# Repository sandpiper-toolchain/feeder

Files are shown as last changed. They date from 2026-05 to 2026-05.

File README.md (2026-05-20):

# feeder

Open-source sediment feeders for geomorphology experiments.

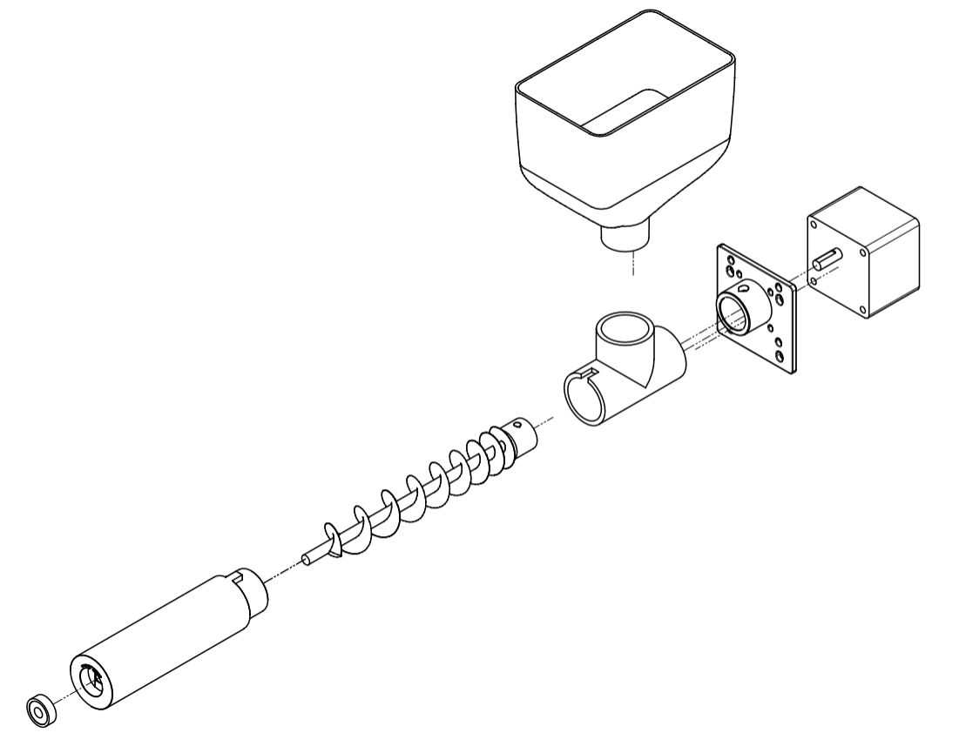
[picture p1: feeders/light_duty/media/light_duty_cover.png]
exploded light duty feeder


## Getting started

A single feeder setup consists of a "motor assembly" and a "feeder".
To the maximum extent possible any of the described motor assemblies and feeders can be mixed-and-matched to create a complete feeder setup.

Motors may be controlled manually, or with the provided microcontroller code.

This repository provides the information to build the following:

**feeders**

* [light_duty](/feeders/light_duty/)
* ~standard~ (not yet available)

**motor assemblies**

* [manual_control_ac_motor](/motor_assemblies/)
* ~multi_control_dc_motor~ (not yet available)

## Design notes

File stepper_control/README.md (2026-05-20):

# Stepper Motor Sediment Feeder

> **Note:** This README was generated with AI assistance. While it reflects the actual code and hardware used in this project, some details (library versions, port names, wiring notes) may be inaccurate or become outdated. Verify against the source files and your hardware before following any instructions.

A CircuitPython firmware package for the Raspberry Pi Pico that drives a laboratory sediment feeder. A stepper motor controls a hopper/auger mechanism to dispense sediment at a programmable, adjustable rate. Speed and direction can be set manually via a rotary encoder and hardware buttons, or remotely from a PC over USB serial.

---

## Hardware Components

| Component | Description | Notes |
|---|---|---|
| Raspberry Pi Pico | RP2040 microcontroller | Standard Pico (not Pico W) |
| Stepper motor | NEMA stepper with step/dir/enable driver | Tested at 400 steps/rev |
| Stepper motor driver | A4988, DRV8825, or similar | Must expose STEP, DIR, and ENA pins |
| [Adafruit I2C Rotary Encoder Breakout](https://www.adafruit.com/product/4991) | Seesaw-based encoder with button | Product ID 4991, I2C addr `0x36` |
| SSD1306 OLED display | 128×64 monochrome, I2C | I2C addr `0x3D` |
| 3× momentary push buttons | Through-hole or panel-mount | Pulled down internally via Pico GPIO |

---

## Pin Wiring

| Pico Pin | Function |
|---|---|
| GP4 (SDA) | I2C data — shared bus for OLED and encoder |
| GP5 (SCL) | I2C clock — shared bus for OLED and encoder |
| GP8 | Button C — stop/exit program |
| GP9 | OLED reset |
| GP10 | Button B — reverse motor direction |
| GP15 | Button A — toggle motor enable |
| GP18 | Stepper STEP (PWM output) |
| GP19 | Stepper DIR |
| GP22 | Stepper ENA |

The three GPIO buttons connect between the pin and GND; the firmware configures them with internal pull-downs, so they read HIGH when pressed.

---

## Software Requirements

### CircuitPython

Install **CircuitPython 9.2.x** on the Pico:

1. Download the UF2 from [circuitpython.org](https://circuitpython.org/board/raspberry_pi_pico/).
2. Hold BOOTSEL on the Pico and plug in USB; drag the UF2 to the `RPI-RP2` drive.

### Libraries

Copy the following from the [Adafruit CircuitPython Bundle](https://circuitpython.org/libraries) into the `lib/` folder on the Pico:

| Library | Source |
|---|---|
| `adafruit_seesaw/` | Adafruit CircuitPython Seesaw |
| `adafruit_displayio_ssd1306.py` | Adafruit CircuitPython DisplayIO SSD1306 |
| `adafruit_display_text/` | Adafruit CircuitPython Display Text |
| `adafruit_bus_device/` | Adafruit CircuitPython BusDevice |
| `adafruit_motor/` | Adafruit CircuitPython Motor |
| `adafruit_pixelbuf.mpy` | Adafruit CircuitPython Pixelbuf |
| `adafruit_ht16k33/` | Adafruit CircuitPython HT16K33 |

The following are built into CircuitPython and require no separate install: `pwmio`, `digitalio`, `displayio`, `busio`, `supervisor`, `usb_cdc`.

---

## Project Files

| File | Purpose |
|---|---|
| `boot.py` | Runs at power-on; enables dual USB CDC endpoints (console + data) |
| `stepper.py` | `Stepper` class — low-level motor control via PWM and GPIO |
| `code.py` | Main application — display, encoder, buttons, serial command loop |

---

## Getting Started

1. Wire up the hardware per the pin table above.
2. Flash CircuitPython and copy the `lib/` folder to the Pico.
3. Copy `boot.py`, `stepper.py`, and `code.py` to the root of the Pico (`CIRCUITPY` drive).
4. The Pico will reboot and start the feeder firmware automatically.

The OLED will show **"Feeder initialized."** briefly, then display live status:

```
speed: 0.080 Hz
motor is: OFF
direction is: CW
enable pin is: ON
```

---

## Manual Controls

| Control | Action |
|---|---|
| Rotate encoder knob | Increase / decrease motor speed |
| Press encoder knob | Toggle motor start / stop |
| Button A (GP15) | Toggle motor enable (releases coil torque when OFF) |
| Button B (GP10) | Reverse motor direction (CW ↔ CCW) |
| Button C (GP8) | Exit the program (stops motor cleanly) |

---

## PC-Side Python Setup

To send commands from a PC you need the `pyserial` package. Using a virtual environment keeps this isolated from your system Python.

### Create and activate a venv

**Linux / macOS:**
```bash
python3 -m venv feeder-env
source feeder-env/bin/activate
```

**Windows:**
```bat
python -m venv feeder-env
feeder-env\Scripts\activate
```

### Install dependencies

```bash
pip install pyserial
```

To save the environment for later:
```bash
pip freeze > requirements.txt
```

To restore it on another machine:
```bash
pip install -r requirements.txt
```

### Find the correct serial ports

When the Pico is plugged in, it will appear as two serial ports — one for the console and one for data. To find them:

**Linux:**
```bash
ls /dev/ttyACM*
# typically /dev/ttyACM0 (console) and /dev/ttyACM1 (data)
```

**macOS:**
```bash
ls /dev/tty.usbmodem*
```

**Windows:** Open Device Manager and look under **Ports (COM & LPT)** for two new COM ports.

---

## Remote Control via USB Serial

The Pico exposes two USB serial ports when connected to a PC:

- **Console port** — receives commands and prints debug output.
- **Data port** — returns telemetry responses to `get:` queries.

Send commands as plain text lines (terminated with `\n`) to the **console port**.

### Commands

| Command | Description |
|---|---|
| `speed=<float>` | Set motor speed in rotations per second (e.g. `speed=0.5`) |
| `toggle` | Start or stop the motor |
| `switch_direction` | Reverse motor direction |
| `enable` | Enable motor driver |
| `disable` | Disable motor driver (releases torque) |
| `get:speed` | Query current speed (RPS) — response on data port |
| `get:direction` | Query direction (`-1`=CW, `1`=CCW) — response on data port |
| `get:enabled` | Query enable state (`True`/`False`) — response on data port |
| `get:running` | Query running state (`True`/`False`) — response on data port |
| `stop` | Exit the program |

### Example (Python on PC)

```python
import serial, time

# Adjust port names for your OS (e.g. 'COM3' on Windows, '/dev/ttyACM0' on Linux)
console = serial.Serial('/dev/ttyACM0', timeout=1)
dataport = serial.Serial('/dev/ttyACM1', timeout=1)

console.write(b'speed=0.25\n')   # set 0.25 RPS
time.sleep(0.1)
console.write(b'toggle\n')       # start motor

console.write(b'get:speed\n')
print(dataport.readline())       # b'0.25\n'
```

---

## Stepper Class Reference

`stepper.py` provides the `Stepper` class used by `code.py`, but can be imported into any CircuitPython project:

```python
from stepper import Stepper
import board

s = Stepper(
    step_pin=board.GP18,
    dir_pin=board.GP19,
    ena_pin=board.GP22,
    steps_per_rev=400,   # match your motor/driver microstepping setting
    speed_sps=800        # initial speed in steps per second
)

s.start()              # begin stepping
s.speed_rps(0.5)       # change to 0.5 RPS
s.change_direction()   # reverse
s.stop()               # halt and disable
```

`steps_per_rev` should match your driver's microstepping setting (e.g. 400 for half-step, 1600 for 1/8, 3200 for 1/16).

---

## License

MIT License — Eric Barefoot, 2025. Encoder example adapted from Adafruit (John Furcean, 2021, MIT).

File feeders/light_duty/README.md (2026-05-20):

# light duty feeder

This feeder was designed to deliver rice grains for "rice pile" type experiments.

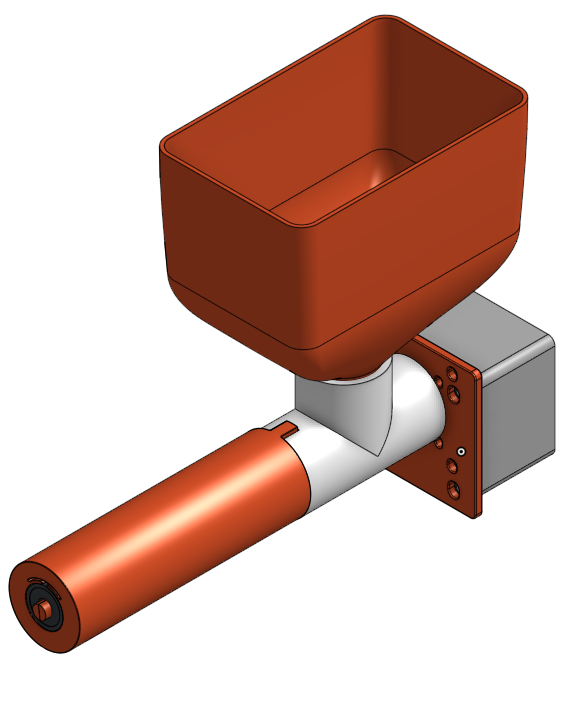
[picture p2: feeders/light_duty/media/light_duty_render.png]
light duty feeder assembly rendered


A driving design principle for the light duty feeder is extremely low cost.
This has been achieved by using an off-the-shelf plumbing part for the main feeder housing, and standard hardware and mounting configurations. 

This feeder may not be suitable for clastic sediments, due to the inherent strength of 3D-printed materials.
The design and print instructions are optimized for easy printing and maximum strength for FDM printing.  

## Bill of Materials

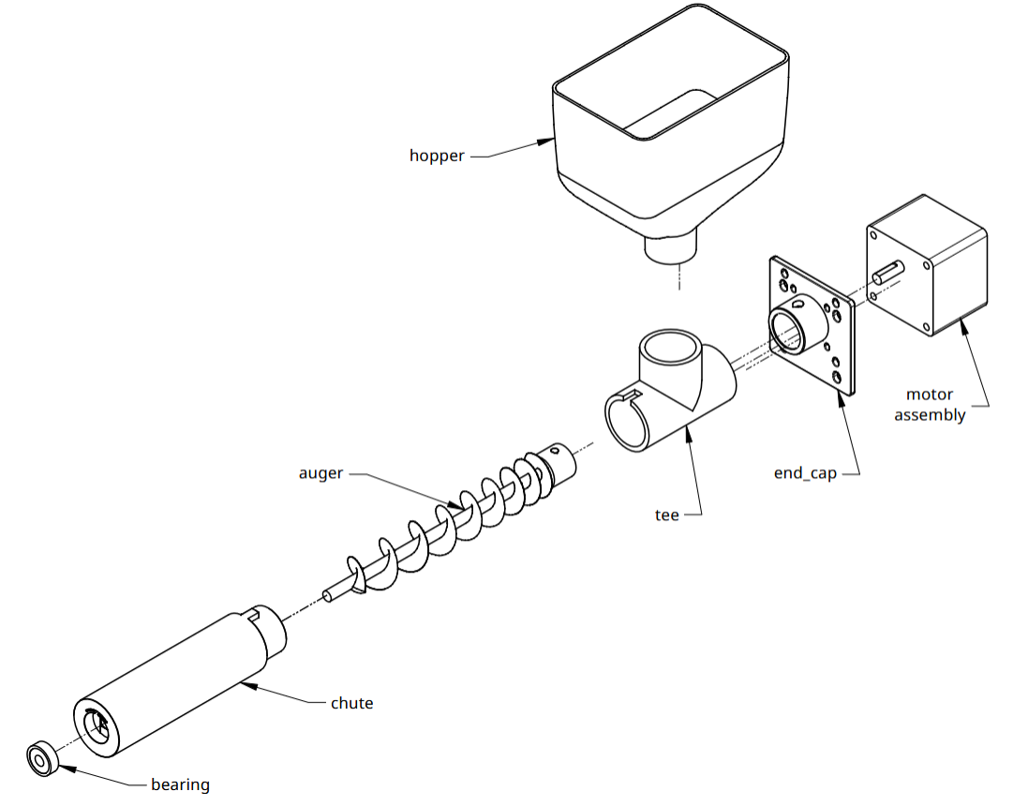
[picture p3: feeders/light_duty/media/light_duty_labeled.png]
exploded light duty feeder


* 1 x 1 inch schedule 40 PVC tee connector
* 1 x 608RS bearing
* 1 x M4 nut
* 1 x M4 by 5 mm set screw
* [a motor assembly](/motor_assemblies/) with 8 mm output shaft, and appropriate mounting screws
* 3D-printed components (see below)
* CA glue

You also will need standard tools, likely including Allen wrenches, a hacksaw, a screwdriver, etc.

## Instructions and build notes

### Build notes

* The `end_cap` has mounting holes for NEMA 17 and 23 stepper motors, as well as the AC motor listed in the motor assembly section. 
* The `chute` has a mounting point for a 608 bearing. The feeder may function fine without the bearing, but will have considerably more play in the auger shaft.
* The `auger` is designed for a motor assembly with an 8 mm D shaft.

### Printing

**.stl files are found above in the folder vX.X.**

All components can be printed in material of your choice. 
PLA works well, but PETG or ABS may provide stronger components. 
Both textured and flat build plates will be fine. 
All parts can be printed with 15% infill, except the `auger`, which should be printed at 100% infill.

* The `auger` halves should be printed with the flat side down, and then glued together with CA glue. 
  * This part should be printed at 100% infill.
  * If you would like to print the `auger` in a resin printer, an unsplit auger .stl file is also provided.
* The `chute` should be printed on the bearing side. 
* The `end_cap` should be printed on motor side.
* The `hopper` should be printed on the wide end (i.e., upside down). 

### Assembly

After printing all components:
1. Using a saw, cut a small notch in end of one side of the long edge of the PVC tee, with the notch on the same side as the short side of the tee. The notch should be larger than the corresponding block on the `chute` (cut a ~7 mm  wide by ~11 mm deep notch); it is okay if the notch is slightly larger than needed creating some play, but try to keep it at tight as possible.
1. Insert the bearing into the back of the `chute`.
1. Insert the M4 nut into the back of the `auger`. You can use some CA glue to hold the nut in place, but it is not necessary.  
1. Attach the `end_cap` to motor face using appropriate screws and mounting holes.
1. Slide the `auger` onto the motor output shaft, and tighten M4 set screw onto flat of D output shaft.
1. Slide the `chute` over the `auger`, and carefully align block with notch in PVC tee and `auger` end with inner bearing hole. Some force may be required to seat the `auger` end into the inner bearing hole.
1. Insert the `hopper` into PVC tee.
1. Fill `hopper` with granular material, provide power to motor assembly.

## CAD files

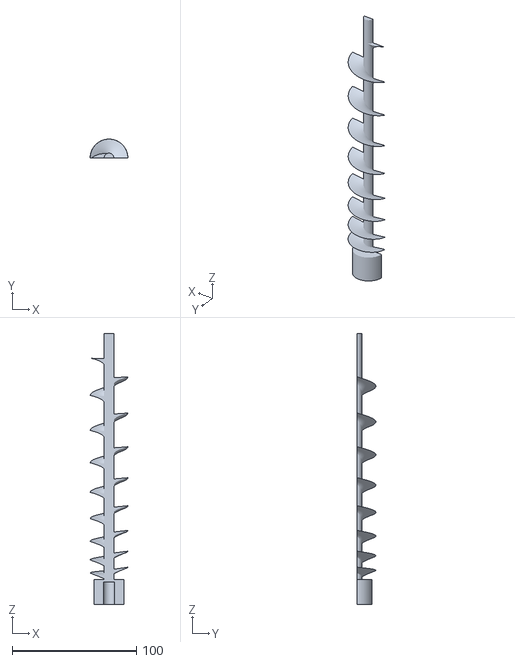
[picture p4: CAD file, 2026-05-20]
feeders/light_duty/v0.1/auger_1.stl
30.4 x 15.2 x 218.0

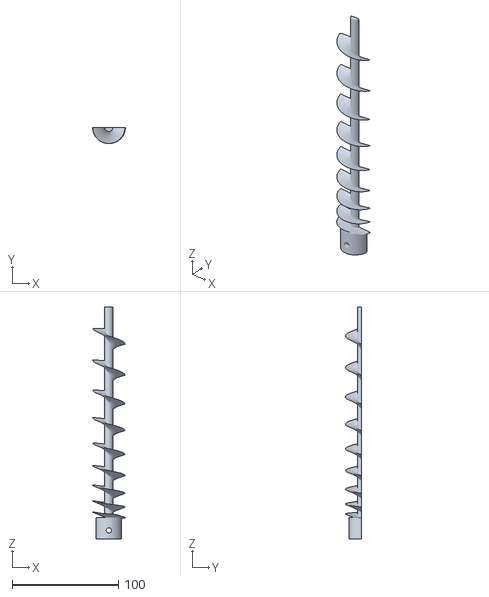
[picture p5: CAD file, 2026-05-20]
feeders/light_duty/v0.1/auger_2.stl
30.8 x 15.3 x 218.0

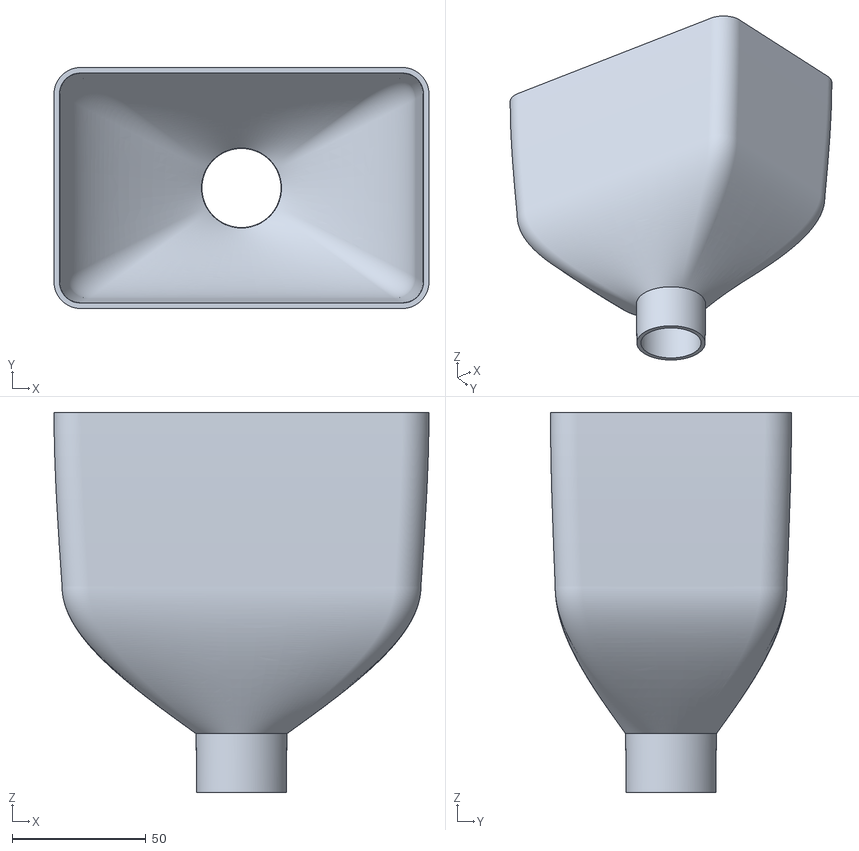
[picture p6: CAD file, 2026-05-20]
feeders/light_duty/v0.1/hopper.stl
140.0 x 90.0 x 142.0

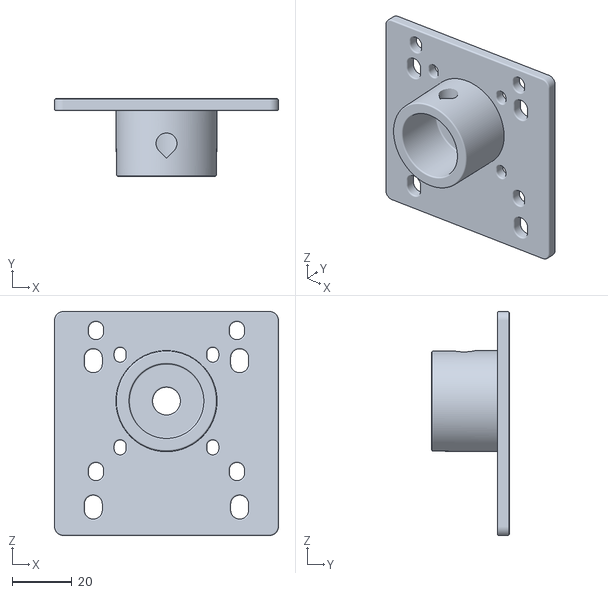
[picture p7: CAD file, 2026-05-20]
feeders/light_duty/v0.1/end_cap.stl
75.0 x 26.0 x 75.0

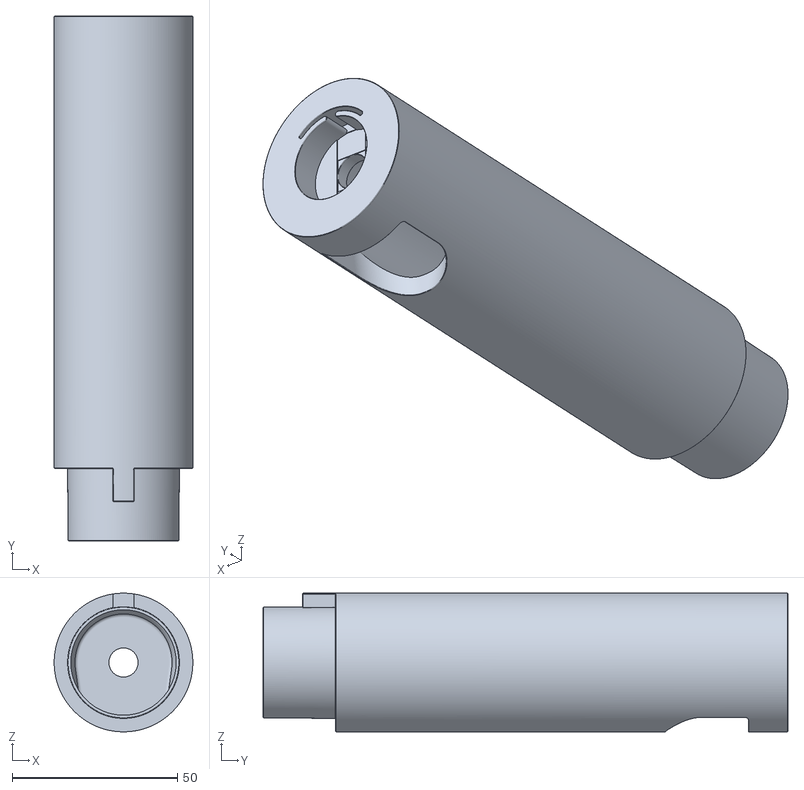
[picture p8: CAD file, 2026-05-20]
feeders/light_duty/v0.1/chute.stl
42.0 x 159.0 x 42.0

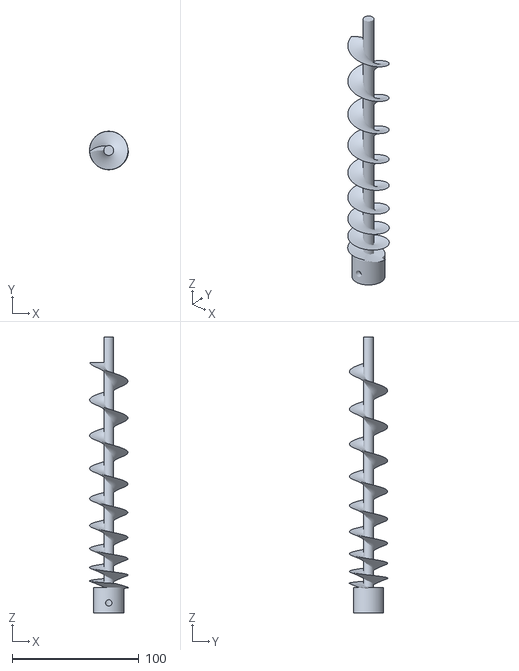
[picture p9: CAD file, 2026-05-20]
feeders/light_duty/v0.1/auger_unsplit.stl
30.8 x 30.5 x 218.0

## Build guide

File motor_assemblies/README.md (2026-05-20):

# motor assemblies

You can use any `motor_assembly` to power any `feeder`, including your own motor assembly that is not listed below.

* We have successfully used DC brushed and brushless motors, AC motors, and stepper motors.
* In general, you want something that can provide a relatively large amount of torque at low RPM.
* In general, you do not need a motor with a top end of more than 100 RPM.

There are many thousands of different motors available on the internet across sites like Amazon, Alibaba, DFRobot, Adafruit, etc. 

## Described assemblies

**manual_control_ac_motor**

You can buy a complete motor assembly that includes a power cord, control knob, and motor mount, and the motor itself. 
For example, [this AC motor from Amazon](https://www.amazon.com/dp/B07WH5V14Z). 

This is probably the easiest motor assembly to "build" to run one of the feeders, because there is essentially zero assembly required.

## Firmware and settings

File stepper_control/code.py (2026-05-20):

"""Sediment feeder controller for Raspberry Pi Pico.

Main application firmware for the laboratory sediment feeder. Manages stepper motor
control, displays real-time status on OLED, handles user input from rotary encoder
and buttons, and accepts remote commands via USB serial for PC integration.

SPDX-FileCopyrightText: 2021 John Furcean
SPDX-License-Identifier: MIT
Modified by Eric Barefoot MIT LICENSE 2025
"""

import board
from time import sleep, monotonic
import digitalio

# USB serial endpoints for remote control and telemetry
from usb_cdc import console as conser
from usb_cdc import data as dataline

from supervisor import runtime

# Disable autoreload to prevent interruption during experiments
runtime.autoreload = False
print(f"AutoReload is {runtime.autoreload=}")

# Stepper motor control (GPIO pins GP18=step, GP19=direction, GP22=enable)
from stepper import Stepper

from adafruit_seesaw import rotaryio, seesaw
from adafruit_seesaw import digitalio as ssdio

s = Stepper(step_pin=board.GP18, dir_pin=board.GP19, ena_pin=board.GP22, steps_per_rev=400)
# TODO: Make steps_per_rev configurable to support different motor types

# Display and input hardware (I2C bus on GP4=SDA, GP5=SCL)
import displayio
import i2cdisplaybus
import adafruit_displayio_ssd1306
import terminalio
from adafruit_display_text import label

displayio.release_displays()

import busio
i2c = busio.I2C(scl=board.GP5, sda=board.GP4)

# Seesaw breakout (addr 0x36) hosts rotary encoder and knob button
seesaw = seesaw.Seesaw(i2c, addr=0x36)

seesaw_product = (seesaw.get_version() >> 16) & 0xFFFF
if seesaw_product != 4991:
    print("Wrong firmware loaded?  Expected 4991")

# Rotary encoder knob button (on seesaw pin 24)
seesaw.pin_mode(24, seesaw.INPUT_PULLUP)
button = ssdio.DigitalIO(seesaw, 24)
button_held = False

# Rotary encoder for speed control
encoder = rotaryio.IncrementalEncoder(seesaw)

# Control buttons on Pico GPIO
# Button A (GP15): Toggle motor enable
# Button B (GP10): Change direction
# Button C (GP8): Stop/exit program
button_a = digitalio.DigitalInOut(board.GP15)
button_a.direction = digitalio.Direction.INPUT
button_a.pull = digitalio.Pull.DOWN

button_b = digitalio.DigitalInOut(board.GP10)
button_b.direction = digitalio.Direction.INPUT
button_b.pull = digitalio.Pull.DOWN

button_c = digitalio.DigitalInOut(board.GP8)
button_c.direction = digitalio.Direction.INPUT
button_c.pull = digitalio.Pull.DOWN

# led = digitalio.DigitalInOut(board.GP25)
# led.direction = digitalio.Direction.OUTPUT

# yellow = digitalio.DigitalInOut(board.GP18)
# yellow.direction = digitalio.Direction.OUTPUT

# redled = digitalio.DigitalInOut(board.GP19)
# redled.direction = digitalio.Direction.OUTPUT

def new_speed(p, spd=1/50):
    """Convert encoder position to motor speed (RPS).

    Maps encoder steps to speed; default spd=1/50 means each encoder step = 0.02 RPS.
    """
    return p * spd

s.dir_pin.value = False  # Set initial direction to clockwise

def wait_pin_change(pin):
    """Wait for a button pin to stabilize (debounce over 20ms)."""
    cur_value = pin.value
    active = 0
    while active < 20:
        if pin.value != cur_value:
            active += 1
        else:
            active = 0
        sleep(0.001)

# Performance timing
t0 = monotonic()
n = 16000
encoder.position = 4
position = encoder.position
s.speed_rps(new_speed(position))
last_position = position

# OLED display setup (SSD1306, 128x64, I2C addr 0x3D)
WIDTH = 128
HEIGHT = 64
BORDER = 5

display_bus = i2cdisplaybus.I2CDisplayBus(i2c, device_address=0x3D)
display = adafruit_displayio_ssd1306.SSD1306(display_bus, width=WIDTH, height=HEIGHT)

# Display group for UI elements
splash = displayio.Group()
display.root_group = splash

color_bitmap = displayio.Bitmap(WIDTH, HEIGHT, 1)
color_palette = displayio.Palette(1)
color_palette[0] = 0xFFFFFF  # White

# bg_sprite = displayio.TileGrid(color_bitmap, pixel_shader=color_palette, x=0, y=0)
# # splash.append(bg_sprite)

# # Draw a smaller inner rectangle
# inner_bitmap = displayio.Bitmap(WIDTH - BORDER * 2, HEIGHT - BORDER * 2, 1)
# inner_palette = displayio.Palette(1)
# inner_palette[0] = 0x000000  # Black
# inner_sprite = displayio.TileGrid(inner_bitmap, pixel_shader=inner_palette, x=BORDER, y=BORDER)
# splash.append(inner_sprite)

# Initialize display with status information
text = f"Feeder initialized."
text_area = label.Label(terminalio.FONT, text=text, color=0xFFFFFF, x=0, y=10)
splash.append(text_area)

sleep(2)
splash.remove(text_area)

# Display labels (updated in real-time in the main loop):
# - Speed (RPS): controlled by rotary encoder or serial command
# - Motor running status: ON/OFF
# - Motor enable status: ON/OFF (soft disable)
# - Direction: CW (clockwise, direction=-1) or CCW (counter-clockwise, direction=1)

text = f"speed: {round(s.rps, 3)} Hz"
speed_splash = label.Label(terminalio.FONT, text=text, color=0xFFFFFF, x=0, y=8)
splash.append(speed_splash)

ison = lambda x: "ON" if x else "OFF" if not x else "Problem..."

text = f"motor is: {ison(s.running)}"
onoff_splash = label.Label(terminalio.FONT, text=text, color=0xFFFFFF, x=0, y=18)
splash.append(onoff_splash)

isenabled = lambda x: "ON" if x else "OFF" if not x else "Problem..."

text = f"enable pin is: {isenabled(s.is_enabled())}"
ena_splash = label.Label(terminalio.FONT, text=text, color=0xFFFFFF, x=0, y=38)
splash.append(ena_splash)

direct = lambda x: "CW" if x < 0 else "CCW" if x > 0 else "Problem..."

text = f"direction is: {direct(s.direction)}"
direction_splash = label.Label(terminalio.FONT, text=text, color=0xFFFFFF, x=0, y=28)
splash.append(direction_splash)

# sleep(2)
# splash.remove(speed_splash)

strcontrolinput = "speed=0.5"  # default speed for testing

print(f"Rice feeder initialized.\nRunning: {s.running}\n")
print(f"Serial connection: {conser.connected}\n")  # type: ignore[reportUnknownVariableType]

# Main control loop
# Handles three input sources:
#   1. Rotary encoder: adjust speed (encoder position -> speed_rps)
#   2. Hardware buttons: toggle motor, change direction, enable/disable, exit
#   3. USB serial commands: remote control from PC (see command handlers below)
# Display updates in real-time whenever state changes.

while True:
    # Read encoder position (controls speed)
    position = encoder.position

    # Check for serial commands from PC
    # Supported commands:
    #   speed=<float>           Set speed in RPS (e.g., speed=0.5)
    #   toggle                  Start/stop motor
    #   switch_direction        Reverse motor direction
    #   enable                  Enable motor driver
    #   disable                 Disable motor driver
    #   get:speed               Query current speed
    #   get:direction           Query current direction (-1=CW, 1=CCW)
    #   get:enabled             Query enable state
    #   get:running             Query running state
    #   stop                    Exit program
    if runtime.serial_bytes_available > 0:
        print("Serial data available")
        controlinput = conser.readline() # type: ignore
        strcontrolinput = controlinput.decode() # type: ignore
        print(f"Received data: {strcontrolinput.split('=')}")

    if position != last_position:
        if position < 0:
            position = 0
            encoder.position = position
        s.speed_rps(new_speed(position))
        # print(f"Position: {position}")
        # print(f"speed: {s.steps_per_sec/s.steps_per_rev} rps")

        # update the speed label
        text = f"speed: {round(s.rps, 3)} Hz"
        speed_update = label.Label(terminalio.FONT, text=text, color=0xFFFFFF, x=0, y=8)
        splash.remove(speed_splash)
        splash.append(speed_update)
        speed_splash = speed_update

        last_position = position
    elif strcontrolinput.split("=")[0] == 'speed':
        # try:
        speed = float(strcontrolinput.split("=")[1])
        position = speed * 50  # update encoder position index to match speed for display
        s.speed_rps(speed)
        print(f"Speed set to: {speed} rps")
        text = f"speed: {round(s.rps, 3)} Hz"
        strcontrolinput = ""
        speed_update = label.Label(terminalio.FONT, text=text, color=0xFFFFFF, x=0, y=8)
        splash.remove(speed_splash)
        splash.append(speed_update)
        speed_splash = speed_update
        # except ValueError:
            # print("Invalid speed value received")

    # Rotary encoder knob button: toggle motor start/stop
    if not button.value and not button_held:
        button_held = True
        if not s.running:
            print('start')
            s.start()
        else:
            s.stop()
            print('stop')
        text = f"motor is: {ison(s.running)}"
        onoff_update = label.Label(terminalio.FONT, text=text, color=0xFFFFFF, x=0, y=18)
        splash.remove(onoff_splash)
        splash.append(onoff_update)
        onoff_splash = onoff_update

    if button.value and button_held:
        button_held = False

    if strcontrolinput.strip() == 'toggle':
        if not s.running:
            print('start')
            s.start()
        else:
            s.stop()
            print('stop')
        text = f"motor is: {ison(s.running)}"
        onoff_update = label.Label(terminalio.FONT, text=text, color=0xFFFFFF, x=0, y=18)
        splash.remove(onoff_splash)
        splash.append(onoff_update)
        onoff_splash = onoff_update
        strcontrolinput = ""
    
    # Button B (GP10): reverse motor direction
    if button_b.value:
        wait_pin_change(button_b)
        print("Button B Pressed - change direction")
        s.change_direction()
        text = f"direction is: {direct(s.direction)}"
        direction_update = label.Label(terminalio.FONT, text=text, color=0xFFFFFF, x=0, y=28)
        splash.remove(direction_splash)
        splash.append(direction_update)
        direction_splash = direction_update

    if strcontrolinput.strip() == 'switch_direction':
        s.change_direction()
        text = f"direction is: {direct(s.direction)}"
        direction_update = label.Label(terminalio.FONT, text=text, color=0xFFFFFF, x=0, y=28)
        splash.remove(direction_splash)
        splash.append(direction_update)
        direction_splash = direction_update
        strcontrolinput = ""

    # Button A (GP15): toggle motor enable (soft disable, releases coil torque)
    if button_a.value:
        wait_pin_change(button_a)
        print("Button A Pressed - toggle enable pin")
        e = s.ena_pin.value
        s.enable(bool(e^1))
        text = f"enable pin is: {isenabled(s.is_enabled())}"
        ena_update = label.Label(terminalio.FONT, text=text, color=0xFFFFFF, x=0, y=38)
        splash.remove(ena_splash)
        splash.append(ena_update)
        ena_splash = ena_update

    if strcontrolinput.strip() == 'enable':
        s.enable(True)
        text = f"enable pin is: {isenabled(s.is_enabled())}"
        ena_update = label.Label(terminalio.FONT, text=text, color=0xFFFFFF, x=0, y=38)
        splash.remove(ena_splash)
        splash.append(ena_update)
        ena_splash = ena_update
        strcontrolinput = ""
    elif strcontrolinput.strip() == 'disable':
        s.enable(False)
        text = f"enable pin is: {isenabled(s.is_enabled())}"
        ena_update = label.Label(terminalio.FONT, text=text, color=0xFFFFFF, x=0, y=38)
        splash.remove(ena_splash)
        splash.append(ena_update)
        ena_splash = ena_update
        strcontrolinput = ""

    # Button C (GP8): exit program
    if button_c.value:
        wait_pin_change(button_c)
        print("Button C Pressed - stop program")
        break

    # Serial command: stop program
    if strcontrolinput.strip() == 'stop':
        print("stop program")
        strcontrolinput = ""
        break

    # Serial query commands: return current state via data endpoint
    if strcontrolinput.split(":")[0] == 'get':
        if strcontrolinput.split(":")[1].strip() == 'speed':
            dataline.write(f"{s.rps}\n".encode()) # type: ignore
        elif strcontrolinput.split(":")[1].strip() == 'direction':
            dataline.write(f"{s.direction}\n".encode()) # type: ignore
        elif strcontrolinput.split(":")[1].strip() == 'enabled':
            dataline.write(f"{s.is_enabled()}\n".encode()) # type: ignore
        elif strcontrolinput.split(":")[1].strip() == 'running':
            dataline.write(f"{s.running}\n".encode()) # type: ignore
        else:
            print("Unknown get command")
        strcontrolinput = ""

    n += 1

# Performance diagnostics: total runtime and cycle time
t1 = monotonic()

print(n)
print(f"time elapsed: {t1-t0}\ntime per cycle = {1000 * (t1-t0)/n}ms")

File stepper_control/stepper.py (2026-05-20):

# import board
from pwmio import PWMOut
# from time import sleep, monotonic
import digitalio

class Stepper:
    """Controls a NEMA stepper motor for the sediment feeder hopper/auger.

    Manages motor speed, direction, and enable state via PWM and GPIO pins.
    Used on Raspberry Pi Pico to drive the sediment dispenser mechanism."""
    def __init__(self, step_pin, dir_pin, ena_pin, steps_per_rev=3200, speed_sps=800, invert_dir=False, invert_enable=False, timer_id=-1):
        """Initialize the stepper motor with GPIO pins and parameters.

        Args:
            step_pin: PWM pin for step pulses (frequency controls speed)
            dir_pin: Digital pin for rotation direction
            ena_pin: Digital pin to enable/disable motor
            steps_per_rev: Microsteps per full revolution (typically 1600-3200)
            speed_sps: Initial speed in steps per second
            invert_dir: Flip direction logic if motor rotates backwards
            invert_enable: Flip enable logic if wired inverted
        """

        if not isinstance(step_pin, PWMOut):
            step_pin = PWMOut(step_pin, frequency=speed_sps, duty_cycle=0, variable_frequency=True)
        if not isinstance(dir_pin, digitalio.DigitalInOut):
            dir_pin = digitalio.DigitalInOut(dir_pin)
            dir_pin.direction = digitalio.Direction.OUTPUT
        if (ena_pin != None) and (not isinstance(ena_pin, digitalio.DigitalInOut)):
            # print("setting up enable pin")
            ena_pin = digitalio.DigitalInOut(ena_pin)
            ena_pin.direction = digitalio.Direction.OUTPUT
 
        self.step_pin = step_pin
        self.dir_pin = dir_pin
        self.ena_pin = ena_pin
        self.invert_dir = invert_dir
        self.invert_enable = invert_enable

        self.min_hz = 10

        self.direction = -1 # counting direction, 1 for counter-clockwise, -1 for clockwise

        self.enable(True)
        
        self.steps_per_sec = speed_sps
        self.steps_per_rev = steps_per_rev
        self.rps = self.steps_per_sec / self.steps_per_rev

        self.running = False
        self.enabled = self.is_enabled()
        
        
    def speed(self, sps):
        """Set motor speed in steps per second, with a minimum frequency floor.

        Adjusts PWM frequency to control rotation speed; clamped to min_hz to
        avoid stalling. Updates cached speed values for RPM calculations.
        """

        if sps >= self.min_hz:
            self.step_pin.frequency = int(sps)
            self.sec_per_step = 1/sps
            self.steps_per_sec = self.step_pin.frequency
            self.rps = self.step_pin.frequency / self.steps_per_rev
        else:
            self.step_pin.frequency = self.min_hz
            self.sec_per_step = 1/self.min_hz
            self.rps = self.step_pin.frequency / self.steps_per_rev
    
    def speed_rps(self, rps):
        """Set motor speed in rotations per second.

        Convenience method for users who think in RPM; converts to steps/sec
        and delegates to speed().
        """
        self.speed(rps*self.steps_per_rev)

    def start(self):
        """Enable the motor and begin stepping at the current speed."""
        self.enable(True)
        self.step_pin.duty_cycle = 2**14  # 25% duty cycle for step pulses
        self.running = True

        # if self.direction>0:
        #     self.dir_pin.value = 1
        #     self.step_pin.duty_cycle = 2**15  # 50% duty cycle
        # elif self.direction<0:
        #     self.dir_pin.value = 0
        #     self.step_pin.duty_cycle = 2**15
        # else:
        #     self.step_pin.duty_cycle = 0
        #     print("Stepper: start called with d=0, no steps will be taken")

    def stop(self):
        """Halt stepping and disable the motor to release torque."""
        self.step_pin.duty_cycle = 0
        # self.dir_pin.value = 0  # Reset direction pin to low when stopping
        self.enable(False)
        self.running = False

    def change_direction(self):
        """Reverse the motor rotation direction and update tracking state."""
        d = self.dir_pin.value
        self.dir_pin.value = bool(d^1)  # Toggle direction pin
        self.direction = self.direction * -1

    def enable(self, e=True):
        """Enable or disable the motor driver. When disabled, motor coils are de-energized."""
        self.ena_pin.value = bool(0^e)

    def is_enabled(self):
        """Return whether the motor is currently enabled."""
        return bool(self.ena_pin.value)

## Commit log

2026-05-19 framework and root readme.
2026-05-19 placeholder motor assembly folder
2026-05-20 typos, add motor assembly page and first assembly text.
2026-05-20 link to motor assemblies
2026-05-20 commit v0.1 stl files.
    [auger_1.stl, auger_2.stl, auger_unsplit.stl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]
2026-05-20 add context for cad file location.
2026-05-20 Add stepper_control module and bundled Adafruit libs
    - Add controller scripts: `boot.py`, `code.py`, `stepper.py`, and `README.md`
    - Add bundled Adafruit MicroPython libraries under `lib/` for display, motor, and seesaw support
